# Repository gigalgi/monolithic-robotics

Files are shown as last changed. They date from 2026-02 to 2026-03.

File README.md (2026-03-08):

# Monolithic Robotics

**A compliant mechanism framework for anthropomorphic robot design — from a single joint to a full arm, printed in one piece.**






---

## The Core Idea

Most robotic arms are built from a collection of rigid links, discrete motors, and separate joints — each component manufactured and assembled independently. This approach works, but it carries real costs: mechanical complexity, assembly error, maintenance overhead, and a fundamental disconnect from how biological limbs actually move.

This framework starts from a different premise: **what if the entire structure — every joint, every link, every flexure — was one continuous compliant body?**

The answer is Monolithic Robotics. Every joint in this framework is derived from a single atomic unit: the **UMoBIC joint**, a two-flexure cross hinge with an embedded rolling contact element, synthesized from synovial joint biomechanics using the [FACT framework](https://samueli.ucla.edu/people/jonathan-hopkins/) developed by Prof. Jonathan Hopkins at UCLA. The same joint, stacked and scaled, produces every degree of freedom from fingertip to shoulder — and the entire assembly can be fabricated in a single 3D printing session.

> *"Our future work aims to design and create monolithic structures that mimic human anatomy and dexterity — including the integration of sensors embedded in the joints — creating anthropomorphic limbs in a single print session."*
> — Galvis Giraldo, ICCAS 2024

---

## From One Joint to a Full Arm

The framework is built on a single insight: the human synovial joint is **scale-invariant**. The same rolling contact + compliant flexure principle governs every joint in the body — from the distal interphalangeal joint of the finger (a few millimeters) to the shoulder (tens of centimeters). By matching this biology, one joint design becomes a universal building block.

```
UMoBIC Joint  (atomic unit, 1-DOF compliant revolute)
    │
    ├── × 2 stacked     →  MCP joint   (finger base)
    ├── × 3 stacked     →  PIP joint   (finger middle)
    ├── × 1             →  DIP joint   (fingertip)
    ├── × 4 universal   →  Wrist       (2-DOF)
    ├── scaled 50mm     →  Elbow       (1-DOF)
    └── scaled 70mm     →  Shoulder    (1-DOF)
```

The result: a full anthropomorphic arm with 6 degrees of freedom at the arm level, 7 per finger, and 5 for the thumb — all derived from the same joint geometry, fabricated as one monolithic structure.

<div align="center">
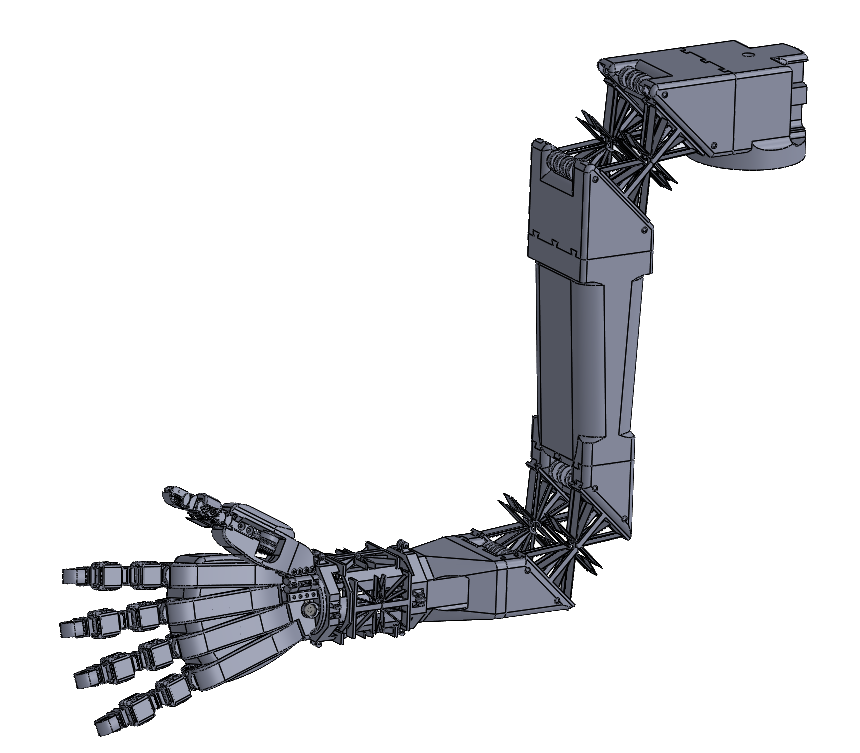
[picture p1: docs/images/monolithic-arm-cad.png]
Monolithic Anthropomorphic Arm CAD
  
  <br><em>Monolithic Anthropomorphic Arm — CAD overview. Shoulder, elbow, wrist, hand and fingers as one continuous structure.</em>
</div>

---

## The UMoBIC Joint

The joint is the foundation of everything. It was designed using the **six-step FACT synthesis process**, beginning from the geometry of a human synovial joint and working through freedom and constraint topology analysis to arrive at a manufacturable compliant structure.

<div align="center">
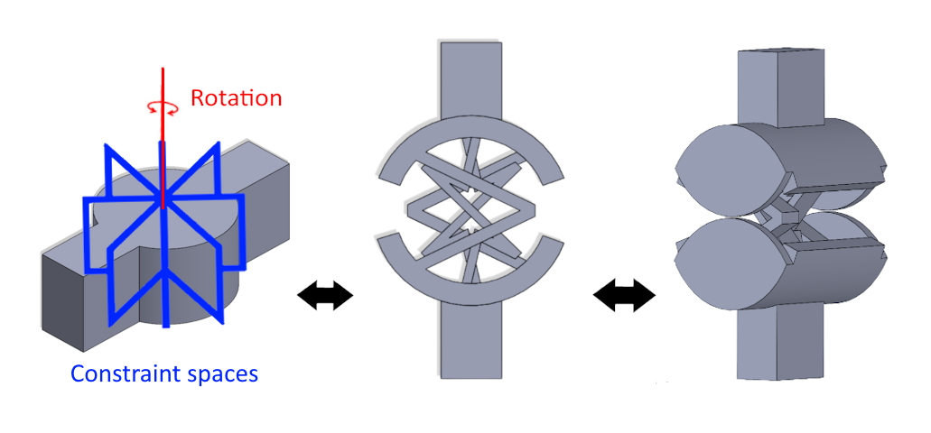
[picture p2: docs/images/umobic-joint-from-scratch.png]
  
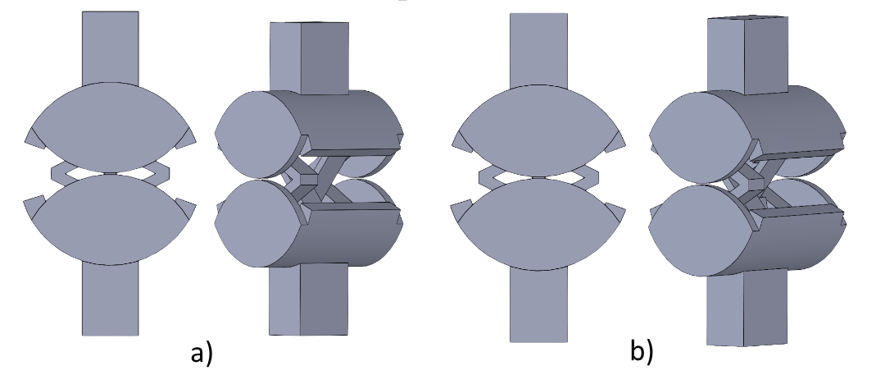
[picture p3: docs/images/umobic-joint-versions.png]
UMoBIC Joint Version 1 and 2
  
  <br><em>UMoBIC joint — Version 1 (left) and Version 2 (right), each with embedded contact rolling element. Version 2 reduces peak stress by 15.25% and increases range of motion.</em>
</div>

**Key properties (PETG, 10N load):**
| Property | Version 1 | Version 2 |
|---|---|---|
| Peak stress | 6.8 × 10⁷ N/m² | 5.9 × 10⁷ N/m² |
| Max displacement | 6.073 mm | 6.673 mm |
| Max strain | 1.488 × 10⁻² | 1.167 × 10⁻² |
| Range per joint | ~40° | ~40° |
| Stress threshold | 60 MPa | 60 MPa |

The embedded **contact rolling joint** solves the cable compression problem: cable-driven systems exert axial compressive loads on flexure blades during actuation, accelerating fatigue. The rolling contact surface redistributes these loads through rolling rather than sliding, dramatically extending durability.

<div align="center">
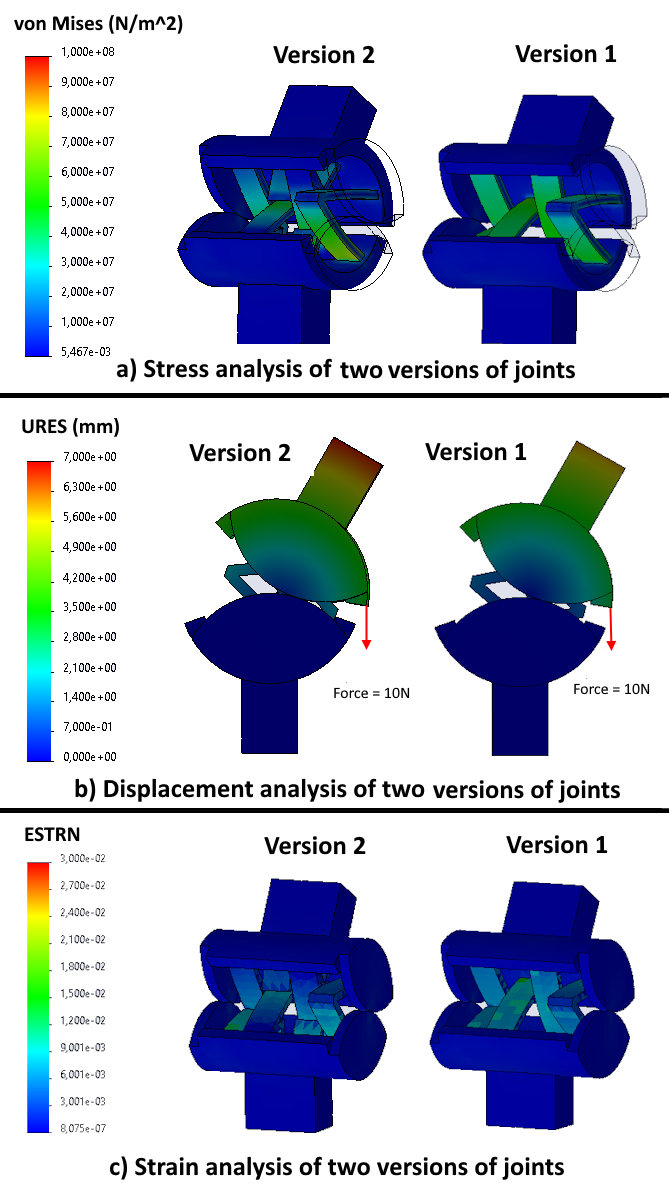
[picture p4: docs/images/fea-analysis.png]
FEA Analysis
  
  <br><em>Finite Element Analysis — von Mises stress (a), displacement (b), and strain (c) for both joint versions.</em>
</div>

---

## Serial Stacking — How One Joint Becomes a Finger

A single joint provides ~40° of flexion. Human finger joints require 70°–110°. The solution is serial stacking: flexures in series combine their degrees of freedom, and the cumulative range matches biological targets without changing the joint design.

<div align="center">
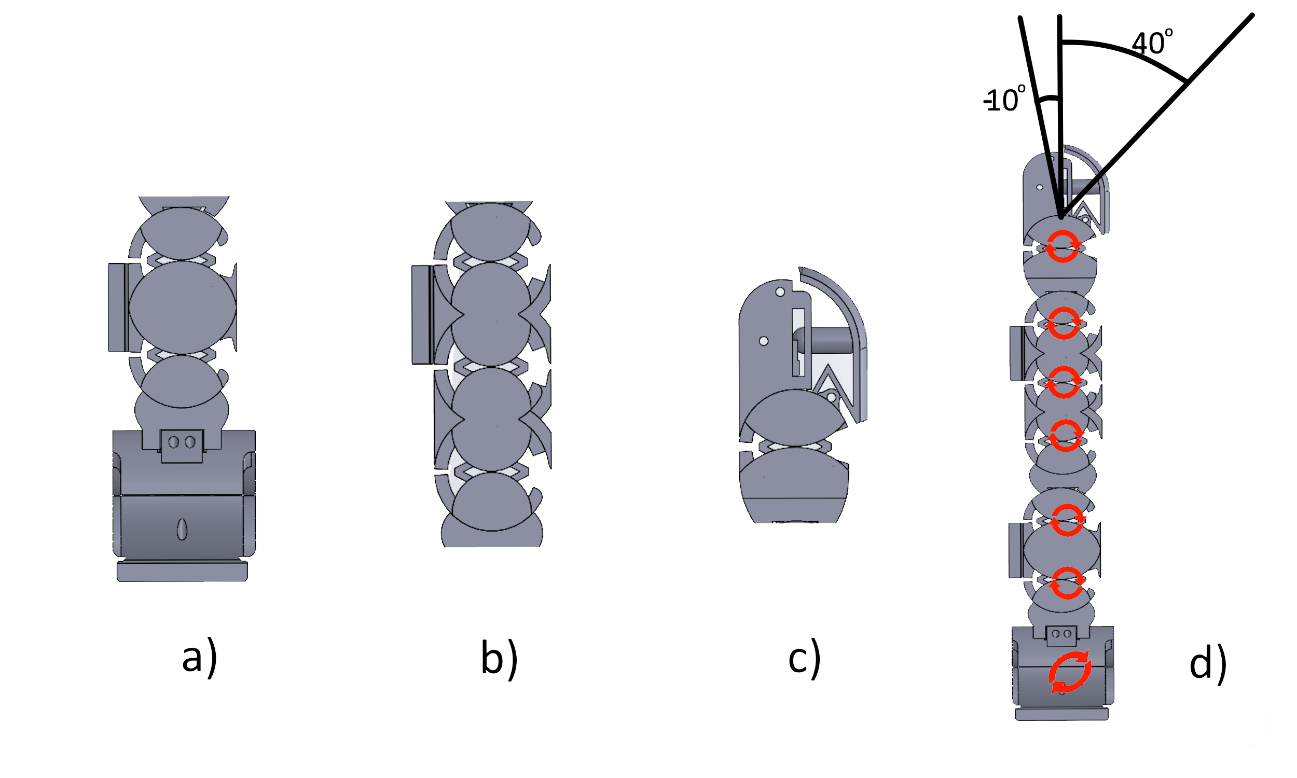
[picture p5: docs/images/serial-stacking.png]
Serial stacking strategy
  
  <br><em>MCP (a), PIP (b), DIP (c), and full finger with 7 DOF (d). Red circles mark each degree of freedom.</em>
</div>

| Phalanx | Joint | Stacking | DOF |
|---|---|---|---|
| Proximal | MCP | 2 joints + 1 offset 90° | 3 |
| Middle | PIP | 3 joints | 3 |
| Distal | DIP | 1 joint | 1 |
| **Total** | | | **7** |

---

## The UMoBIC Finger

The finger is the first complete implementation of the framework — every mechanism in it was also designed using FACT: the skin modules, the fingertip force transmission, and the differential actuation system.

<div align="center">
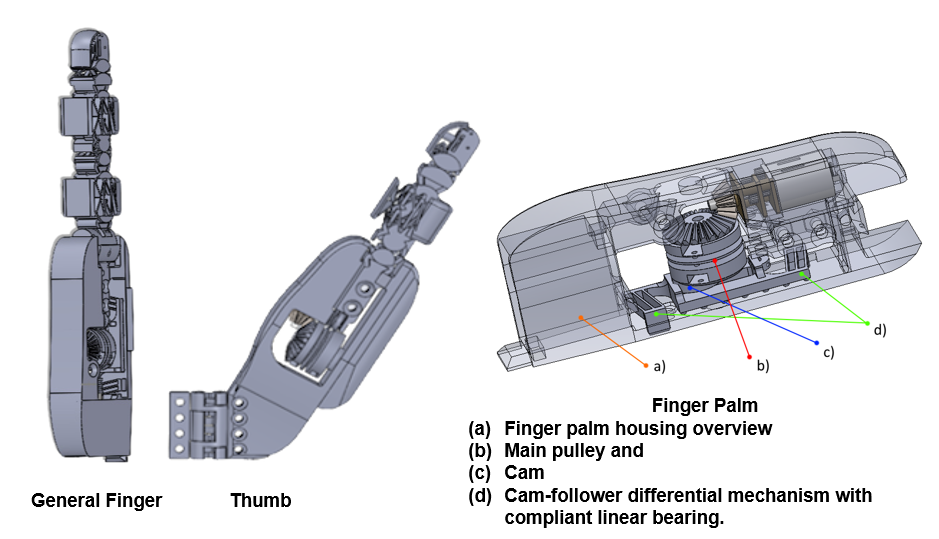
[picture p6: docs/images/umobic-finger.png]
UMoBIC Finger overview
  
  <br><em>UMoBIC-Finger internal structure: cable-driven system, cam-follower differential mechanism, skin modules, and fingertip force transmission.</em>
</div>

**Design summary:**
- 7 degrees of freedom (6 flexion/extension + 1 abduction-adduction)
- Two grasping modes: full underactuated wrap + independent tip control
- Integrated skin modules (4-DOF compliant surface)
- Fingertip force transmission to FSR-400 sensor (0–10 N range)
- Cam-follower differential mechanism for independent DIP control
- Single print session, standard PETG, any desktop FDM printer
- **~85 grams, ~$8 USD** including actuators and sensors

---

## Hand and Wrist

The same joint, extended with larger redundant flexure blades, produces the wrist mechanism — a 2-DOF universal joint configuration. Five UMoBIC fingers plus an opposable thumb assemble into the full anthropomorphic hand.

<div align="center">
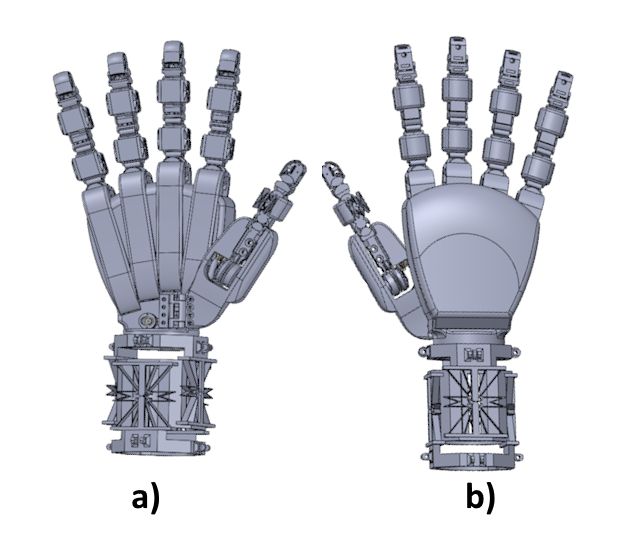
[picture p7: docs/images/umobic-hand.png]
UMoBIC Hand
  
  <br><em>Modular anthropomorphic hand — dorsal (a) and palmar (b) views. Fingers and thumb attach via snap-fit connections secured with M3 screws.</em>
</div>

---

## Simulation and Kinematics

The finger's cable-driven, underactuated design produces highly nonlinear kinematics — cable elasticity and friction prevent purely analytical modeling. Two approaches were compared:

- **Continuum robotics model**: accurate at low angles, diverges at high angles
- **LSTM neural network**: trained on motion capture data, R² = 0.9998 across full range

<div align="center">
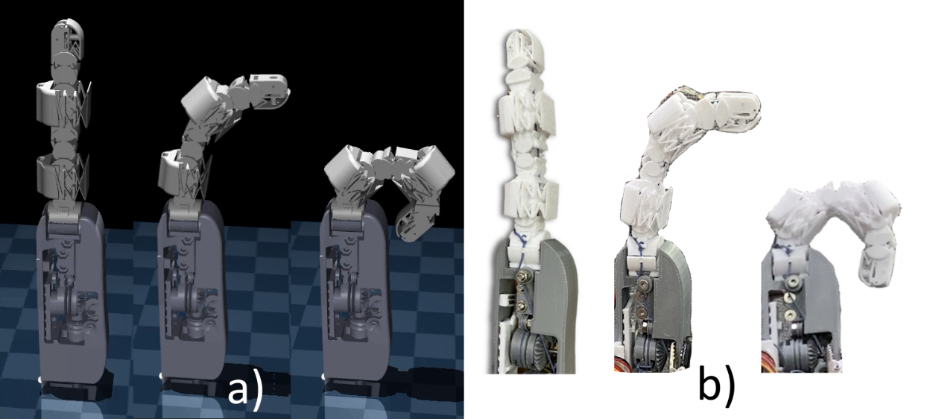
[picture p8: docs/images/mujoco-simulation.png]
MuJoCo simulation vs real prototype
  
  <br><em>MuJoCo simulation (a) vs real prototype (b) — three poses across the range of motion.</em>
</div>

The LSTM model serves as a **joint angle observer**, estimating the motor pulley angle θ required for a given fingertip position (x, y). This feeds an impedance controller for compliant force control during grasping.

---

## Prototype

<div align="center">
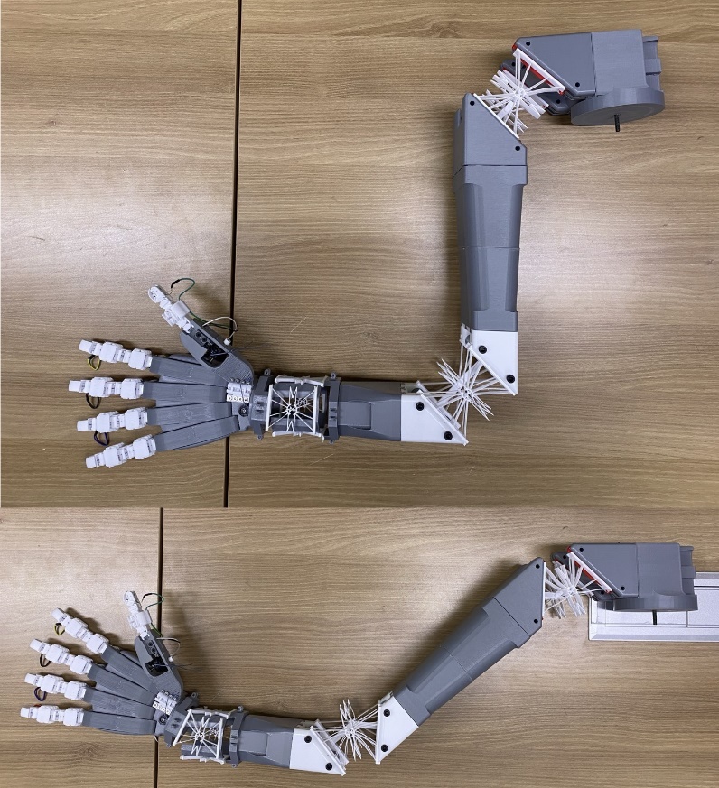
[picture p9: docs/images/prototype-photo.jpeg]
Physical prototype
  
  <br><em>Physical prototype — monolithic anthropomorphic arm with hand, two poses. Fabricated with PETG and PLA on desktop FDM printers.</em>
</div>

---

## Repository Structure

```
monolithic-robotics/
├── docs/
│   ├── umobic-finger-technical-report.pdf   ← Full joint & finger design document
│   └── images/                              ← Design figures
├── joints/
│   └── cad/                                 ← UMoBIC joint CAD files (v2) and extended joints
└── README.md
```

**Related repositories:**

| Repo | Description |
|---|---|
| [open-yta-hand](../open-yta-hand) | Full implementation: finger → hand → wrist. Control code, firmware, MuJoCo, LSTM IK, motion capture |
---

## Publications

**Master's Thesis** — Sungkyunkwan University, 2024
> *Monolithic Robotics with Cognitive AI: A Compliant Mechanism-Based Anthropomorphic Arm Design for Semantic Autonomous Manipulation*
> Gilberto Galvis Giraldo
> [[SKKU Repository]](https://dcollection.skku.edu/srch/srchDetail/000000181091?localeParam=en)

**ICCAS 2024**
> *Design of a Modular Anthropomorphic Hand with Integrated Monolithic Compliant Fingers and Wrist Joint*
> Gilberto Galvis Giraldo, Arpan Ghosh, Tae-Yong Kuc
> 24th International Conference on Control, Automation and Systems, Jeju, Korea
> doi:10.23919/iccas63016.2024.10773068. [[Paper]](https://ieeexplore.ieee.org/document/10773068)

**Technical Report** — 2026
> *UMoBIC-Finger: An Underactuated Monolithic Bio-inspired Compliant Robotic Finger*
> Gilberto Galvis Giraldo
> [[PDF]](docs/umobic-finger-technical-report.pdf)

---

## Foundation

The joint synthesis methodology builds on the **FACT framework** (Freedom, Actuation and Constraint Topologies) developed by Prof. Jonathan Hopkins at UCLA. FACT provides a geometric, visual approach to designing parallel flexure systems with specified degrees of freedom.

> Hopkins, J.B. and Culpepper, M.L. — *Synthesis of multi-degree of freedom, parallel flexure system concepts via freedom and constraint topology (FACT)*, Precision Engineering, 2010.

---
## 🔧 Work in Progress — Project Tumbaga

*Tumbaga* is a parametric design generator for FACT-based compliant joints and flexure chains,
currently under active development as part of this framework.

Named after the gold-copper alloy mastered by pre-Columbian Muisca and Quimbaya goldsmiths —
a material that is neither pure gold nor pure copper, but stronger and more workable than either —
Tumbaga reflects the same idea: combining geometric theory (FACT) with practical fabrication
constraints to produce something more useful than either alone.

**What it does:**
Given a set of design requirements, Tumbaga outputs a print-ready STL of a compliant joint or
flexure chain — no CAD software required:

- Degrees of freedom (1-DOF revolute, 2-DOF universal, translational, or combined)
- Target range of motion per joint
- Physical dimensions (length, width, and scale)
- Motion axis orientation
- Material selection (PETG, PLA, TPU) with automatic stress threshold validation

The output is a fully parametric, FEA-informed geometry ready to send directly to any
standard FDM printer — closing the loop between the FACT synthesis methodology documented
in this repository and a physical prototype.

> **Status:** Active development. Not yet released.
> Follow this repository for updates.
---
## Author

**Gilberto Galvis Giraldo**
M.Sc. Electrical and Computer Engineering — Sungkyunkwan University, South Korea

---

## License

MIT License — see [LICENSE](LICENSE) for details.

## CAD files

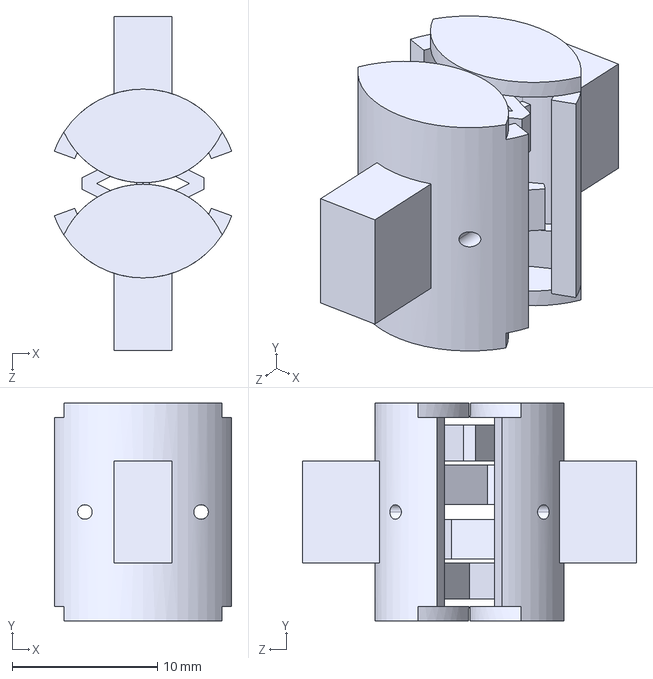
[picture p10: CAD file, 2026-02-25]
joints/cad/finger-rolling-joint.STEP
12.2 x 15.0 x 23.0 mm

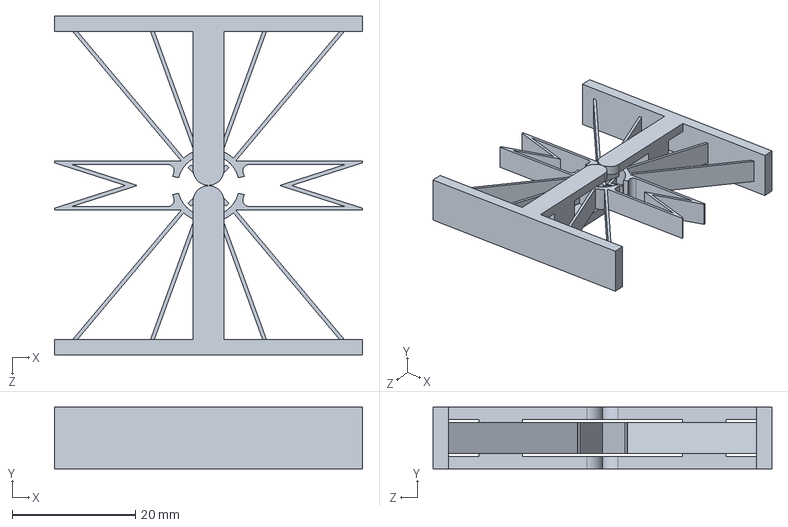
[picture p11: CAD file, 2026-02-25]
joints/cad/extended-serial-two-flexure-cross-hinge-wrist.STEP
50.0 x 10.0 x 55.0 mm

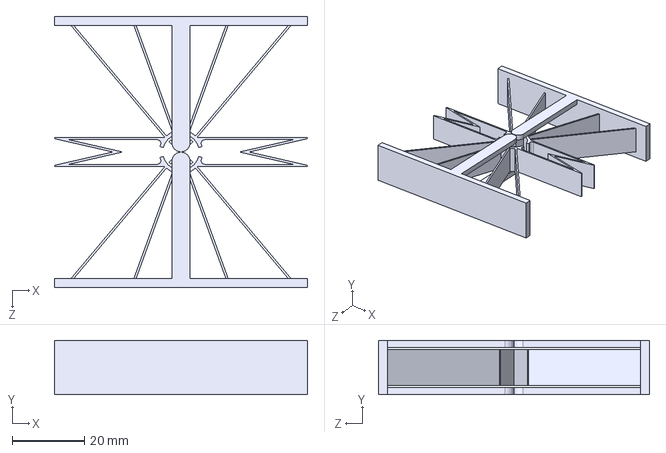
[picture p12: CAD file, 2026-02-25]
joints/cad/extended-serial-two-flexure-cross-hinge-elbow-shoulder.STEP
70.0 x 15.0 x 75.0 mm

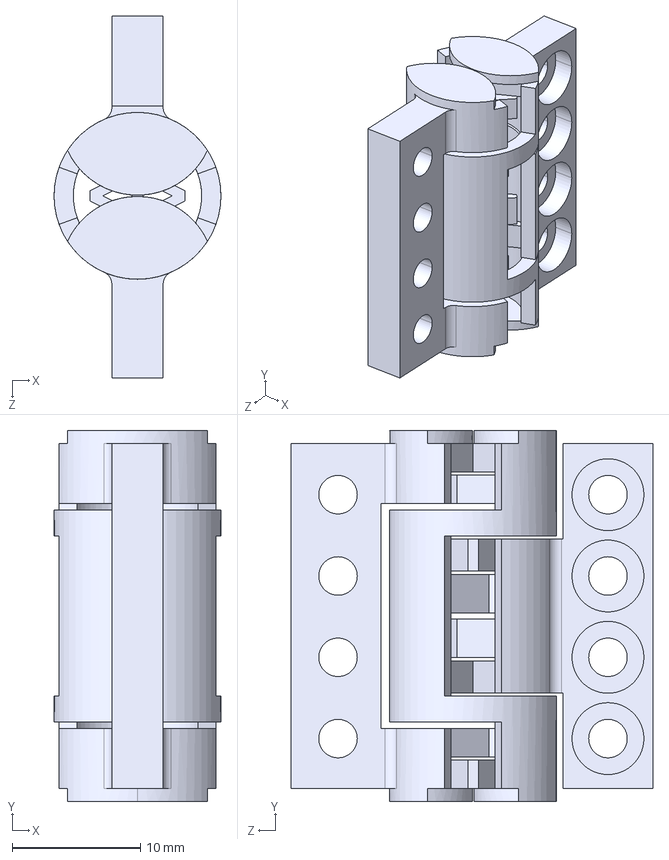
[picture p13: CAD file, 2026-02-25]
joints/cad/parallel-offset-joint-opposable-thumb.STEP
13.0 x 28.9 x 28.2 mm

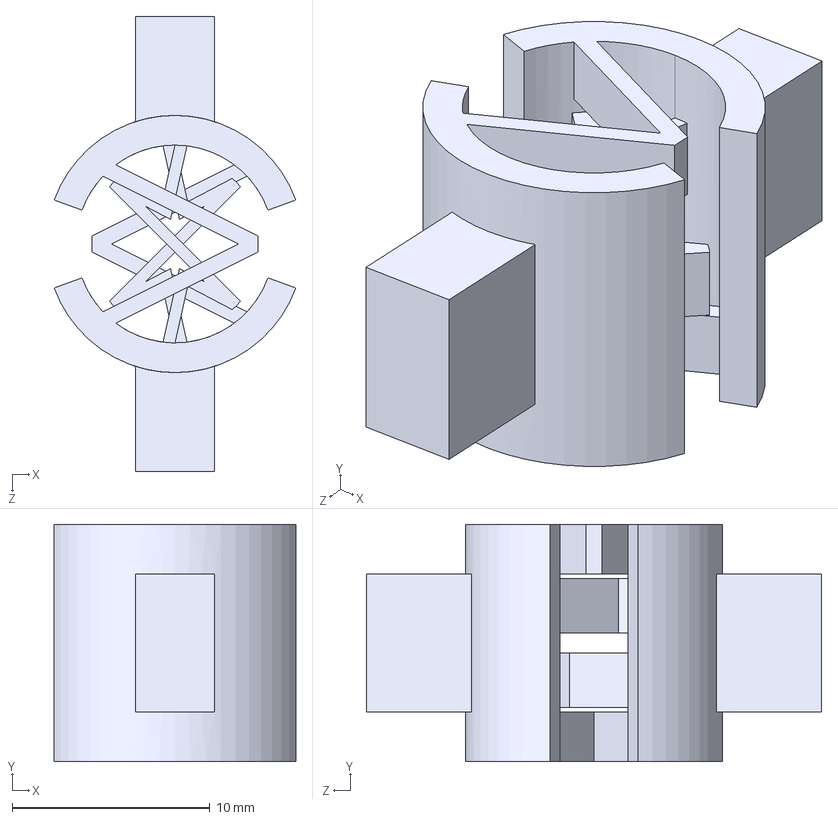
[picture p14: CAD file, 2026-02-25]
joints/cad/finger-joint.STEP
12.2 x 12.0 x 23.0 mm

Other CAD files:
joints/cad/finger-rolling-joint.STL

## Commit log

2026-02-25 image joint from scratch
2026-02-25 joint versions step files
    [extended-serial-two-flexure-cross-hinge-elbow-shoulder.STEP, extended-serial-two-flexure-cross-hinge-wrist.STEP, finger-joint.STEP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]
2026-02-25 joints cad files in .step and .stl
    [extended-serial-two-flexure-cross-hinge-elbow-shoulder.STEP, extended-serial-two-flexure-cross-hinge-wrist.STEP, finger-joint.STEP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]
2026-02-25 joints files
    [extended-serial-two-flexure-cross-hinge-elbow-shoulder.STEP, extended-serial-two-flexure-cross-hinge-wrist.STEP, finger-joint.STEP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]
2026-02-25 joints cad files .step plus .stl
    [extended-serial-two-flexure-cross-hinge-elbow-shoulder.STEP, extended-serial-two-flexure-cross-hinge-wrist.STEP, finger-joint.STEP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]
